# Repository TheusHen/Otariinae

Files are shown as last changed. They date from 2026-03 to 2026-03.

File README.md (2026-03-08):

# SeaLion (Otariinae)

SeaLion is my smart aquarium project. It started as “automate a few aquarium tasks” and turned into a full embedded system: custom PCB, separate controller boards, 3D structure, telemetry, relay control, local logging, aquaponics expansion, and a visual status matrix.

The project is intentionally split into two boards:

- **WhaleShark**: the main **ESP32** board that handles Wi‑Fi, API, time sync, automation, and system orchestration.
- **Flux**: the auxiliary **RP2040** board that handles local relays, the **MAX7219 8×8 matrix**, MicroSD logging, and hardware-side failsafe behavior.

I did it this way on purpose. I wanted networking and high-level logic on the main board, while the second board stays focused on the things that need to remain deterministic and safe near the hardware.

---

## What this project does

The goal is to keep the aquarium stable with as little manual work as possible.

That includes:

- continuous circulation
- water and environment monitoring
- relay control for pumps and other loads
- a local matrix display for loading, timers, warnings, and system state
- aquaponics expansion support
- local MicroSD logging
- remote control and telemetry through an HTTP API
- internet time sync through the ESP32 instead of an RTC on Flux

The aquaponics expansion in V1 is simple on purpose. It is basically a switchable timed peristaltic pump that pulls water from the aquarium and waters the plants. That logic lives in the automation layer and runs through a dedicated Flux relay output.

---

## Architecture

| Block | Controller | Role |
|---|---|---|
| WhaleShark | ESP32 | Wi‑Fi, API, NTP, automation, sensor aggregation, policy |
| Flux | RP2040 | Relay control, MAX7219 rendering, MicroSD logging, failsafe |
| Matrix | MAX7219 | Boot animations, status icons, scrolling text, timers |
| Aquaponics module | Flux relay output | Timed watering of the plant bed |

### Why this split exists

The ESP32 is the system brain. It is much better for:

- network access
- NTP time synchronization
- exposing an API
- coordinating all modules
- future dashboard integration

Flux is the hardware-side executor. It is better for:

- direct relay outputs
- keeping outputs alive in a safe state if the main board disappears
- driving the matrix without blocking the network stack
- logging locally on MicroSD

That separation also helps wiring. The noisy hardware can stay near the board that is meant to switch it.

---

## MAX7219 matrix

Flux controls an **8×8 matrix through the MAX7219**.

This matrix is not just decorative. It is used to display:

- loading during boot
- Wi‑Fi / ready / alert states
- timer countdowns
- short scrolling messages
- icons for pump, water, warning, and plant state

The firmware maps the matrix logically according to the schematic convention you used:

- rows: `ROW0` to `ROW7`
- columns: `COL7` to `COL0`

That means the firmware intentionally mirrors the logical X axis so the matrix behaves like the schematic view instead of whatever random hardware orientation would otherwise appear on the first try.

---

## Current V1 behavior

### Main aquarium pump

The main circulation pump is treated as a **normally-on output**.

That is the safest default for keeping water moving and helping filtration and oxygen exchange. In automatic mode, the firmware keeps it enabled unless there is a condition that strongly suggests protecting hardware from dry run, such as a low-level alarm.

### Aquaponics pump

The aquaponics expansion is handled by a dedicated Flux relay.

Default V1 policy:

- enabled during daytime window
- runs in short timed pulses
- skipped if the aquarium is in a low-level condition
- controlled by WhaleShark, switched by Flux

Those values are easy to change in the config files once the real flow rate is tested.

---

## Firmware layout

### WhaleShark / ESP32

Main responsibilities:

- connect to Wi‑Fi
- sync time from NTP
- read local sensors
- decide relay states
- expose HTTP API endpoints
- optionally protect endpoints with an API secret
- send commands and time updates to Flux over I2C

Important files:

- `firmware/ESP32/include/pins.h`
- `firmware/ESP32/include/config.h`
- `firmware/ESP32/src/main.cpp`

### Flux / RP2040

Main responsibilities:

- receive commands from WhaleShark over I2C
- drive relays
- drive the MAX7219 matrix
- log to MicroSD
- keep safe defaults if communication is lost

Important files:

- `firmware/RP2040(Flux)/include/pins.h`
- `firmware/RP2040(Flux)/include/config.h`
- `firmware/RP2040(Flux)/src/main.cpp`

Protocol notes:

- `firmware/PROTOCOL.md`

Board-to-board wiring notes:

- `docs/CONNECTIONS_FLUX_TO_WHALE.md`

---

## API

WhaleShark exposes a small V1 HTTP API.

Implemented endpoints:

- `GET /api/v1/ping`
- `GET /api/v1/status`
- `GET /api/v1/sensors`
- `POST /api/v1/mode?value=auto|manual|maintenance`
- `POST /api/v1/relay?name=main_pump|aquaponics|spare1|spare2&state=on|off`
- `POST /api/v1/matrix/text?text=HELLO`
- `POST /api/v1/matrix/timer?seconds=90`

### Optional secret

A V1 dashboard does not exist yet, but the firmware already supports an optional API secret.

Set `API_SECRET` in:

- `firmware/ESP32/include/config.h`

If it is set, requests must include:

- `X-API-Key: <your secret>`

If it is left empty, the API is open on the local network.

---

## Inter-board connection

The recommended connection for V1 is:

- I2C
- one interrupt/status line
- one enable/maintenance line
- shared ground
- 5V power from a single source

Recommended mapping:

| WhaleShark (ESP32) | Flux (RP2040) | Purpose |
|---|---|---|
| GPIO21 | GPIO4 | I2C SDA |
| GPIO22 | GPIO5 | I2C SCL |
| GPIO27 | GPIO14 | Flux interrupt / status |
| GPIO26 | GPIO15 | Flux enable / maintenance |
| 5V | VBUS / 5V in | power |
| GND | GND | common reference |

More detail is in:

- `docs/CONNECTIONS_FLUX_TO_WHALE.md`

---

## Mechanical side

The physical design uses a printed upper and lower structure with an acrylic middle body, mounting points, and space for cables, sensors, pumps, and boards.

### Structure 3D

<p align="center">
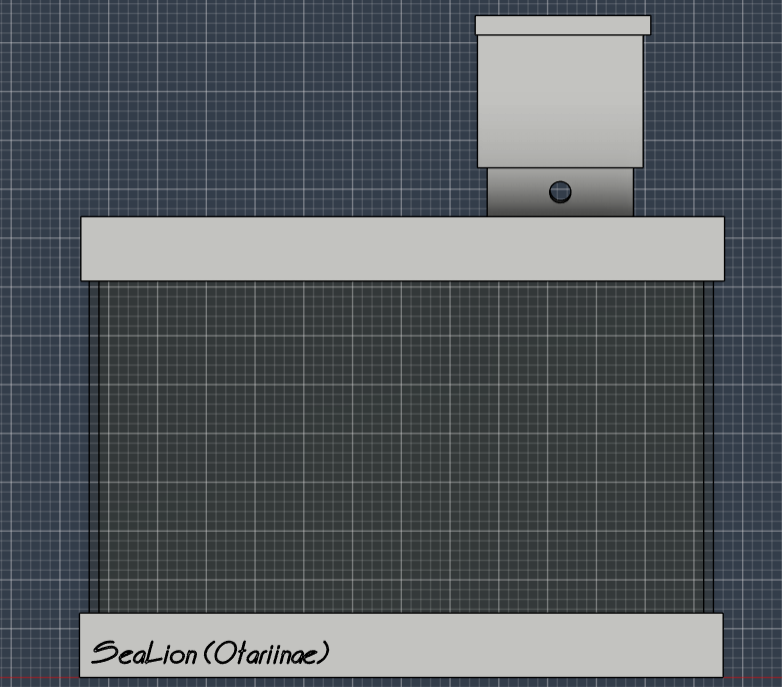
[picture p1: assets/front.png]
Front view
  
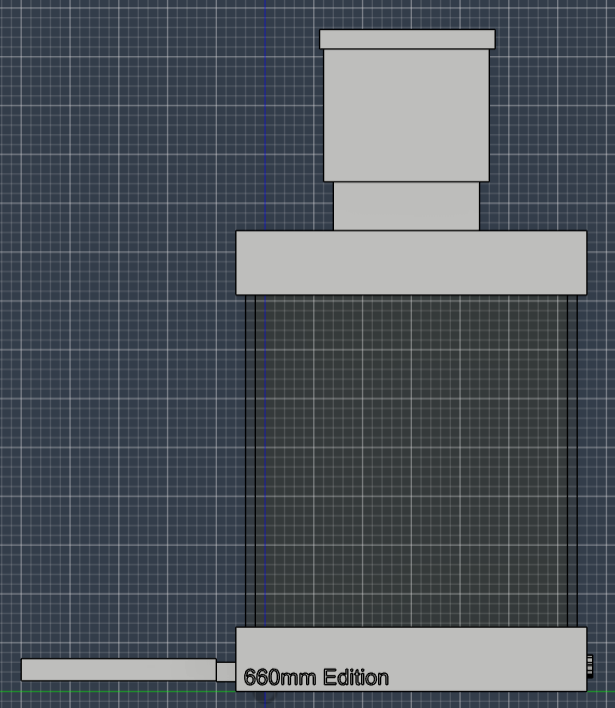
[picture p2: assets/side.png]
Side view
  
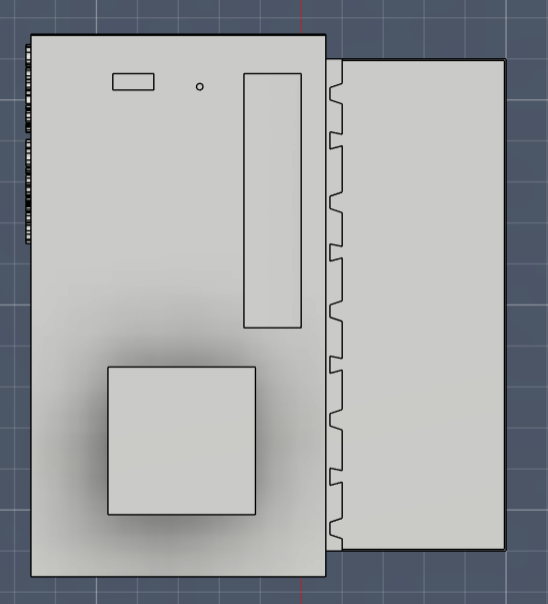
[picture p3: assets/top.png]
Top view
  
</p>

### Electrical bay

<p align="center">
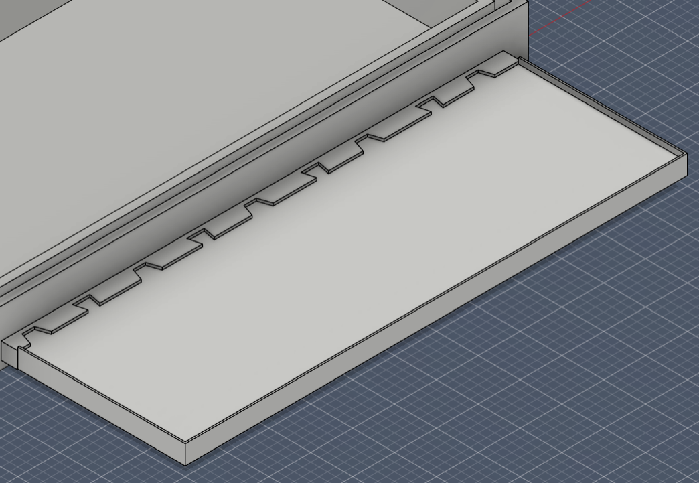
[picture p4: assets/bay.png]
Electrical bay
  
</p>

---

## PCB

### Schematic

<p align="center">
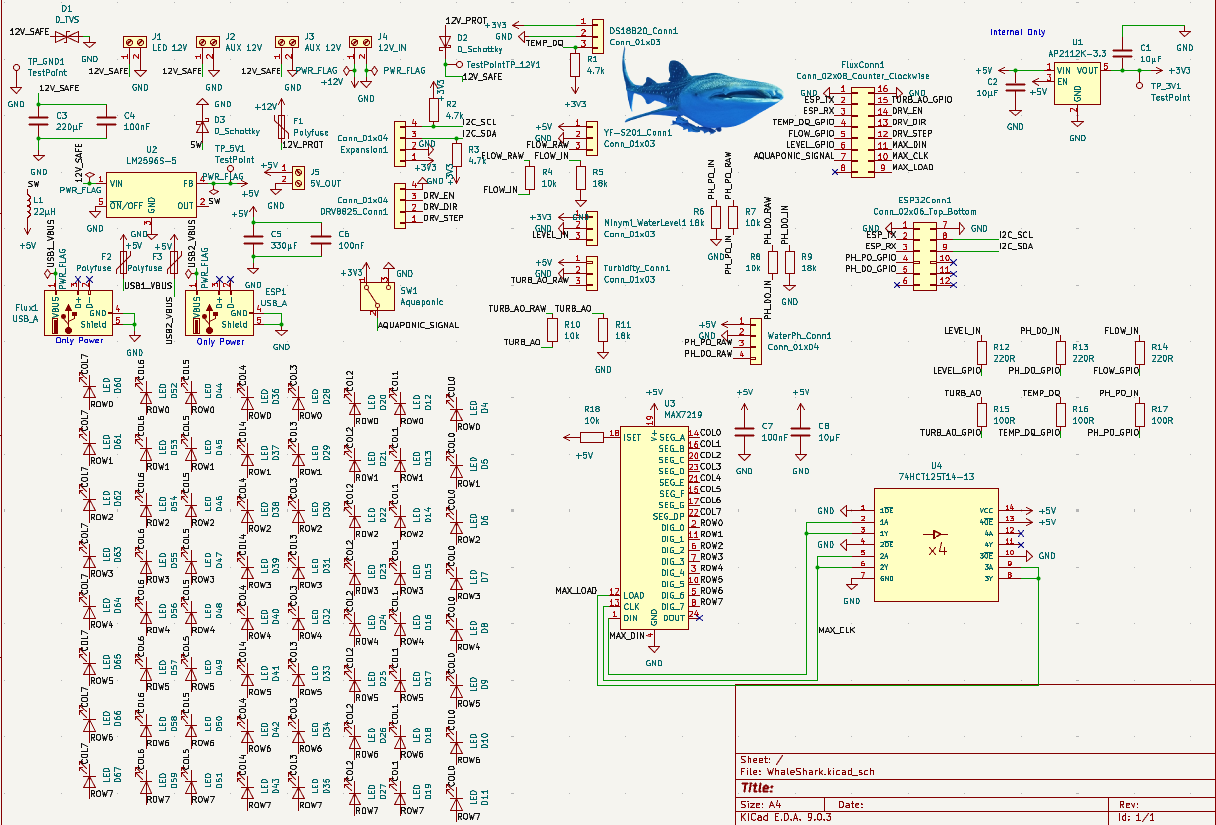
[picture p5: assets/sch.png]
WhaleShark schematic
  
</p>

### Layout

<p align="center">
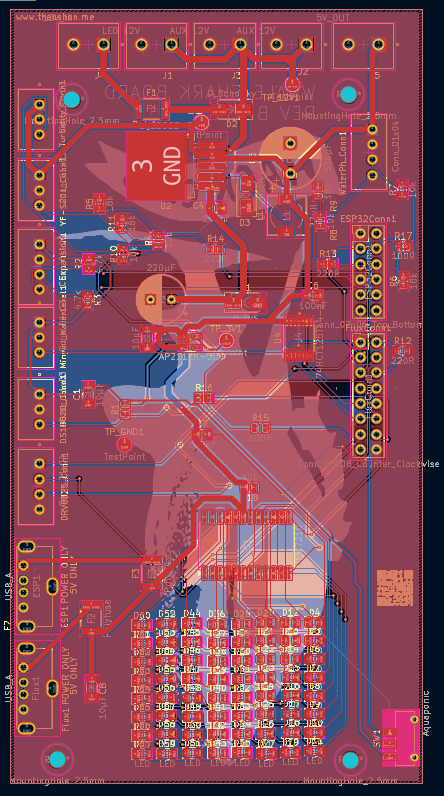
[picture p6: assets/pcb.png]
PCB layout
  
</p>

### Board 3D renders

<p align="center">
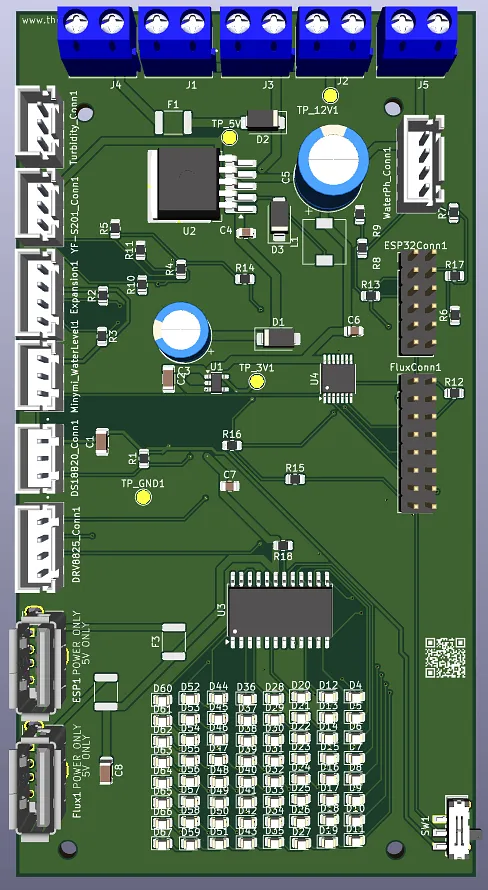
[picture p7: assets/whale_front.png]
PCB 3D front
  
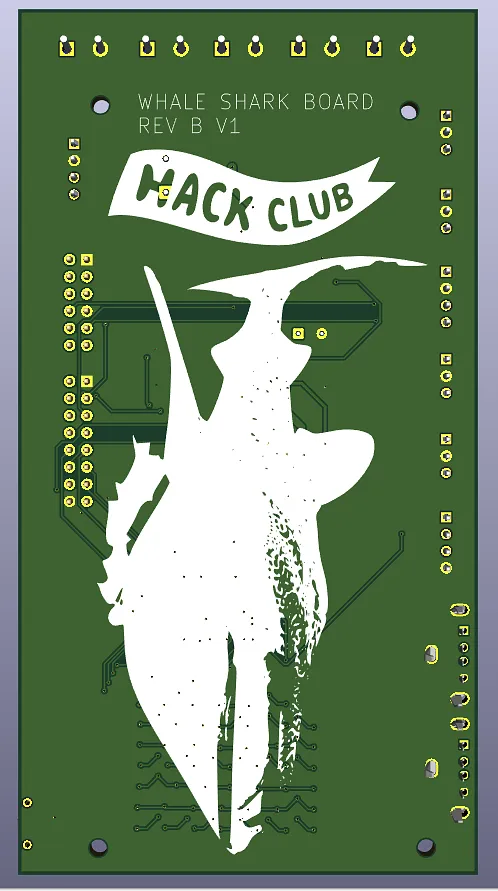
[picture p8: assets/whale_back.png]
PCB 3D back
  
</p>

---

## Notes about calibration

The firmware already includes the structure for:

- pH
- TDS
- turbidity
- water level
- water temperature

The analog conversions are present as practical V1 defaults, but they still need final real-world calibration against the exact probes and boards used in the hardware.

That part is normal. The project can boot, talk, switch, and show state without final calibration, but trustworthy chemistry values need calibration with the physical sensors.

---

## V1 priorities

The current focus is not a cloud product. The priority is:

1. boot reliably
2. connect both boards
3. read sensors
4. keep the aquarium alive safely
5. show useful local feedback on the matrix
6. expose a usable local API
7. leave room for a future dashboard

That is the point of this revision: get a strong first real hardware/software foundation instead of pretending the hard parts do not exist.

https://stpeter.im/writings/essays/publicdomain.html

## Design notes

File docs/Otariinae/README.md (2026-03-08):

# SeaLion — Otariinae (Visão geral do projeto)

SeaLion (edição **Otariinae**) é um aquário inteligente/autônomo com arquitetura embarcada **distribuída**, telemetria completa da água, automação e um módulo de **aquaponia** integrado.

**Fontes neste repositório**
- Escopo (Rev. C): [Need Some Fish — Rev C (Otariinae).md](../../Need%20Some%20Fish%20%E2%80%94%20Rev%20C%20(Otariinae).md)
- Devlog / histórico: [journal.md](../../journal.md)

---

## Nomes

| Item | Nome |
|---|---|
| Projeto | **SeaLion** |
| Edição | **Otariinae** |
| PCB | **WhaleShark** |

---

## Status / histórico (datas absolutas)

- **2026-03-03**: planejamento e “DataBook” Rev. A (ver [journal.md](../../journal.md)).
- **2026-03-04**: 3D (Fusion 360) e release Rev. B (ver [journal.md](../../journal.md)).
- **2026-03-05**: pesquisa e integração de **aquaponia** (ver [journal.md](../../journal.md)).
- **2026-03-06**: esquema e PCB WhaleShark (ver [journal.md](../../journal.md)).
- **2026-03-07**: TODOs / melhorias de power/segurança do PCB (ver [journal.md](../../journal.md)).

---

## Arquitetura eletrônica (distribuída)

A Rev. C adota 3 “blocos” independentes:

- **RP2040 DevBoard (Flux ou compatível)**: controle/IO, sensores, atuadores, **RTC** e **MicroSD**.
- **WhaleShark (PCB)**: distribuição elétrica, regulação, proteção, conectores/headers, drivers.
- **ESP32**: conectividade (Wi‐Fi / BLE / app), comunicação (ex.: UART) com o resto do sistema.

**DevBoard de controle (Flux)**

O projeto foi pensado para utilizar minha devboard custom chamada **Flux**, baseada no **RP2040**, que inclui:

- **Slot Micro SD**
- **Headers de IO expandidos**
- **Interface dedicada com a PCB WhaleShark**

Entretanto, o sistema não depende exclusivamente do **Flux**.

Durante desenvolvimento ou replicação do projeto, qualquer devboard compatível com **RP2040** pode ser utilizada, por exemplo:

- **Raspberry Pi Pico**
- **Pico W**
- **RP2040-Zero**
- outras placas **RP2040** compatíveis

Nesse caso, basta conectar a devboard ao header de controle da **WhaleShark PCB**.

---

## Sistema elétrico (alto nível)

Resumo do caminho de energia:

- Rede **110V** (fora do PCB) → filtro de linha com DPS → fonte **12V/10A (IP67)** → **WhaleShark PCB**
- No WhaleShark:
  - Buck **12V → 5V**
  - Regulador **3.3V**
  - Saídas 12V (LED, AUX, etc.)
  - Alimentação/headers para sensores

---

## Sensores (telemetria)

| Sensor | Função | Modelo/Referência |
|---|---|---|
| DS18B20 | Temperatura | DS18B20 à prova d’água |
| pH | Qualidade química | Módulo sensor + sonda BNC |
| Turbidez | Partículas | Sensor de turbidez (referência Arduino) |
| Fluxo | Circulação | YF‑S201 |
| Nível | Segurança de bomba | Sensor de nível (Minymix) |
| Vazamento | Proteção externa | Sensor Velds (Wi‑Fi, alarme 85 dBa) |

---

## Aquaponia (expansão)

Módulo de aquaponia com irrigação/circulação entre aquário e cultivo, e dosagem (bomba peristáltica).

Mitigações citadas: anti‑sifão, sensores de fluxo e nível, manutenção periódica.

---

## Dosador automático de comida

- Dosador rotativo impresso em 3D acionado por **motor NEMA17**
- Driver **DRV8825** (no WhaleShark)
- Controle de porção por passos do motor + agendamento via RTC (Flux)

---

## Estrutura mecânica (alto nível)

- Peças **3D** (parte superior e inferior)
- Seção transparente em **acrílico (PMMA)** encaixado entre as peças
- Compartimento elétrico integrado (mais rígido e simples)

Detalhes: [3D.md](3D.md)

---

## Onde está cada coisa (repo)

- Escopo (Rev. C): [Need Some Fish — Rev C (Otariinae).md](../../Need%20Some%20Fish%20%E2%80%94%20Rev%20C%20(Otariinae).md)
- Devlog: [journal.md](../../journal.md)
- 3D: pasta [3d](../../3d)
- PCB: [sch/WhaleShark.kicad_sch](../../sch/WhaleShark.kicad_sch) e [pcb/WhaleShark.kicad_pcb](../../pcb/WhaleShark.kicad_pcb)
- Gerbers/drill: [gerbers](../../gerbers) e [drl](../../drl)
- iBOM: [ibom/ibom.html](../../ibom/ibom.html)
- Imagens/renders: [assets](../../assets)

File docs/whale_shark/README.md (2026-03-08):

# WhaleShark PCB

A **WhaleShark** é a PCB de distribuição elétrica/regulação/proteção e interconexão do SeaLion (Otariinae).

Arquivos principais:
- Esquemático: [sch/WhaleShark.kicad_sch](../../sch/WhaleShark.kicad_sch)
- Layout: [pcb/WhaleShark.kicad_pcb](../../pcb/WhaleShark.kicad_pcb)
- iBOM: [ibom/ibom.html](../../ibom/ibom.html)

Fabricação:
- Gerbers: [gerbers](../../gerbers)
- Drill: [drl](../../drl)

Imagens:
- [assets/whale_front.png](../../assets/whale_front.png)
- [assets/whale_back.png](../../assets/whale_back.png)

---

## Parâmetros do PCB (do layout)

- Espessura: **1.6 mm** (ver [pcb/WhaleShark.kicad_pcb](../../pcb/WhaleShark.kicad_pcb))

---

## Blocos/ICs relevantes (confirmados no esquemático)

- Buck 12V→5V: **LM2596S-5**
- LDO 3.3V: **AP2112K-3.3**
- Driver LED: **MAX7219**
- Proteção: TVS (ex.: **D1 = D_TVS**)
- Polyfuses (PTC): **F1, F2, F3**

---

## Conectores de potência (bornes) — nomes no esquemático

- **J4 = 12V_IN** (entrada)
- **J1 = LED 12V** (saída 12V para LEDs)
- **J2 = AUX 12V**
- **J3 = AUX 12V**
- **J5 = 5V_OUT**

> Nota: a Rev. C descreve 2 saídas 12V (LED e AUX). O esquemático atual tem **duas** saídas AUX (J2 e J3). Confirme qual revisão você vai fabricar.

---

## USB-A (alimentação de devboards)

- **Flux1** (USB_A)
- **ESP1** (USB_A)

D+/D− aparecem como “unconnected” no layout (USB usado como alimentação, sem dados).

---

## Nets úteis (do layout)

Veja [pcb/WhaleShark.kicad_pcb](../../pcb/WhaleShark.kicad_pcb) para a lista completa; alguns nomes:

- Alimentação: **+12V**, **+5V**, **+3V3**, **GND**
- Stepper/driver: **/DRV_STEP**, **/DRV_DIR**, **/DRV_EN**, **/SW**
- MAX7219: **/MAX_CLK**, **/MAX_DIN**, **/MAX_LOAD**, **/ROW0..7**, **/COL0..7**
- I2C: **/I2C_SDA**, **/I2C_SCL**
- Aquaponia: **/AQUAPONIC_SIGNAL**
- ESP UART: **/ESP_RX**, **/ESP_TX**
- USB VBUS: **/USB1_VBUS**, **/USB2_VBUS**

---

## Gerbers e drill

- Gerbers: [gerbers](../../gerbers)
- Drill: [drl](../../drl)
- iBOM: [ibom/ibom.html](../../ibom/ibom.html)

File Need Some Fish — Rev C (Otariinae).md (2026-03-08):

# Need Some Fish — Rev. C (Otariinae)

Esse projeto virou praticamente um sistema embarcado completo para aquário inteligente. A ideia original era construir um aquário automático e elétrico do zero, e agora na Rev. C ele conta com: eletrônica dedicada, PCB custom, microcontroladores separados, múltiplos sensores, automação, aquaponia integrada, dosagem automática e conectividade.

---

## Visão geral da evolução

Desde a Rev. B, meu projeto evoluiu bastante. Saí de um conceito mais simples com Arduino ou microcontrolador único + relés + sensores com controle central, para uma arquitetura distribuída profissional com separação clara de responsabilidades, proteção elétrica completa, PCB custom roteada, telemetria da água e um módulo de aquaponia integrado.

---

## Arquitetura eletrônica (distribuída)

A maior mudança desse projeto foi sair de um controle central único para uma **arquitetura distribuída** com três sistemas independentes:

```
RP2040 DevBoard (Flux ou compatível)
        │
        │ IO / sensores / controle
        │
        ▼
WhaleShark PCB (distribuição elétrica)
        │
        │ UART / comunicação
        ▼
      ESP32
  WiFi / BLE / app
```

Separação clara de responsabilidades:

| Sistema | Função |
| --- | --- |
| **RP2040** | Controle de hardware  |
| **ESP32** | Conectividade |
| **WhaleShark** | Distribuição elétrica |

### RP2040 DevBoard (Flux ou compatível)

**DevBoard de controle (Flux)**

O projeto foi pensado para utilizar minha devboard custom chamada **Flux**, baseada no **RP2040**, que inclui:

- **Slot Micro SD**
- **Headers de IO expandidos**
- **Interface dedicada com a PCB WhaleShark**

Entretanto, o sistema não depende exclusivamente do **Flux**.

Durante desenvolvimento ou replicação do projeto, qualquer devboard compatível com **RP2040** pode ser utilizada, por exemplo:

- **Raspberry Pi Pico**
- **Pico W**
- **RP2040-Zero**
- outras placas **RP2040** compatíveis

Nesse caso, basta conectar a devboard ao header de controle da **WhaleShark PCB**.

O **ESP32** cuida exclusivamente de conectividade: Wi-Fi, BLE e integração com app/internet.

A **WhaleShark PCB** faz toda a distribuição elétrica, regulação de tensão e proteção entre os sistemas.

---

## Sistema elétrico (proteção completa)

Saí de um esquema simples de 110V → fonte → sensores para um sistema com proteção completa em cascata:

```
Tomada 110V
     │
Filtro de linha / DPS
     │
Fonte 12V 10A (IP67)
     │
PCB WhaleShark
     │
Buck 12V → 5V
     │
Regulador 3.3V
```

### Proteções implementadas

- **Fusível** na entrada
- **Polyfuse (PTC)** nas saídas
- **Proteção de polaridade** (contra inversão)
- **TVS** (contra surtos)
- **Separação física de tensões** no PCB
- **DPS** no filtro de linha (antes da fonte)

Isso reduz muito o risco de falha elétrica, especialmente considerando que esse projeto trabalha perto de água.

### Caminho completo da energia

```
Tomada Quarto (110V)
  → Chave geral bipolar
    → Filtro de Linha com DPS
      → Fonte AC-DC 12V 10A (IP67)
        → Terminal block do PCB WhaleShark
          → Buck 12V→5V (USBs para Flux + ESP32)
          → Saídas 12V (LED, AUX, Motor)
          → Headers de sensores (3.3V/5V)
```

### Componentes de alimentação

- **Filtro de linha com DPS** — iCLAMPER Energia 5 (127/220V, 10A, 5 tomadas)
- **Fonte AC→DC** — FONTE BLINDADA FC FONTES 12V 10A 120W IP67 FC1210BN
- **Cabo de força** — Rabicho 2p + T 2,50mm Plugue 10A 1,50m 127/220V
- **Chave geral** — Módulo Interruptor Bipolar Simples 25A Inova Pro Class Alumbra

---

## PCB WhaleShark (custom)

Esse é um dos maiores upgrades do projeto. Saí de fios soltos, módulos avulsos e jumpers para uma **PCB custom** com roteamento adequado.

### O que a PCB tem

- Reguladores de tensão integrados
- Headers organizados para cada sensor/atuador
- Drivers integrados (DRV8825 para motor de passo)
- Buck converter com layout correto
- Divisores de tensão seguros
- Pull-ups I2C
- Trilhas de potência grossas
- Distribuição de energia separada por função
- **Test points** para facilitar depuração e manutenção

### Alimentação e proteção (no PCB)

- **Entrada principal:** 1x borne 2 vias (12V_IN)
- **Fusível/Polyfuse (PTC)** na entrada 12V
- **Proteção contra inversão de polaridade** na entrada
- **2x portas USB-A** para alimentar Flux + ESP32 (via DC-DC buck 12V→5V)
- **Polyfuse (PTC)** em 5V por porta

### Saídas 12V (alta corrente)

1. **1x borne 2 vias** — LED 12V
2. **1x borne 2 vias** — AUX 12V (reserva)

### Motor de passo (dosador)

- **Driver DRV8825** (soldado no PCB)
- Conector do motor: **JST-XH 4 vias**

### Headers de sensores

| Sensor | Header |
| --- | --- |
| DS18B20 | 1x 3 vias (V/G/D) |
| YF-S201 (fluxo)  | 1x 3 vias |
| Nível (Minymix) | 1x 3 vias |
| Turbidez | 1x 3 vias |
| Módulo de pH | 1x 3 ou 4 vias |
| I2C (expansão) | 1x 4 vias (V/G/SDA/SCL) |

### Conectores entre placas

- **Flux ↔ WhaleShark (controle):** 1x header 2x8 (16 pinos)
- **ESP32 ↔ WhaleShark (comunicação):** 1x header 2x6 (12 pinos)

Isso coloca meu projeto num nível de engenharia muito mais alto do que módulos soltos com jumper.

---

## Sistema de sensores (telemetria completa)

Saí de monitoramento básico para **telemetria completa da água**. Agora consigo monitorar em tempo real tudo que importa.

| Sensor | Função | Modelo/Referência |
| --- | --- | --- |
| DS18B20 | Temperatura | DS18B20 à prova d'água |
| pH | Qualidade química | Módulo Sensor + pH Eletrodo Sonda BNC |
| Turbidez | Partículas na água | Sensor De Turbidez Arduino |
| Fluxo | Circulação | YF-S201 |
| Nível | Segurança da bomba | Sensor De Nível De Água (Minymix) |
| Vazamento  | Proteção externa | Sensor Velds (WiFi, Alarme 85dBa) |

Com isso consigo:
- **Monitoramento em tempo real** de todos os parâmetros
- **Alarmes** automáticos (vazamento, nível baixo, pH fora da faixa)
- **Histórico** de dados (via SD no Flux)
- **Automação** baseada nas leituras (ex: desligar bomba se nível cair)

---

## Aquaponia (nova adição — Rev. C)

Essa foi uma grande expansão do meu projeto. Agora o sistema também controla um módulo de **aquaponia integrado**:

- **Irrigação** das plantas
- **Circulação de água** entre aquário e área de cultivo
- **Dosagem de nutrientes** (via bomba peristáltica)

### Benefícios

- Reciclagem de nutrientes da água do aquário
- Crescimento de plantas como filtragem natural
- Filtragem biológica complementar

### Riscos que estou tratando

| Problema | Risco | Mitigação |
| --- | --- | --- |
| Sifão | Drenagem reversa | Anti-sifão implementado  |
| Entupimento  | Bloqueio de fluxo | Sensor de fluxo (YF-S201) |
| Evaporação | Queda de nível | Sensor de nível |
| Biofilme | Interferência nos sensores | Manutenção periódica |

Já comecei a tratar o problema de sifão com válvula anti-sifão, e os sensores de fluxo e nível ajudam a detectar os outros problemas automaticamente.

---

## Dosador automático de comida

Meu sistema de dosagem usa um **dosador rotativo impresso em 3D** acionado por motor de passo, muito mais confiável que soluções com servo.

```
Reservatório (tampa vedada)
     │
Dosador rotativo (3D)
     │
Motor NEMA 17
     │
Driver DRV8825 (no PCB)
```

### Vantagens

- **Controle fino de porção** (por passos do motor)
- **Alimentação programada** (via Internet, ESP32)
- **Confiabilidade** muito maior que servo simples (sem travar/fechar portinha)

### Estrutura mecânica do dosador

- No topo, fiz em 3D uma **"bacia"/reservatório** que encaixa num buraco acima da tampa.
- Esse reservatório tem **tampa própria** para isolar a ração da umidade.
- A ração fica totalmente isolada até o dosador rotativo liberar a porção, e então cai para dentro do aquário.

### Componentes

- **Motor** — NEMA 17 1.3A 2,8kg (CNC/Laser/Impressora 3D)
- **Driver** — DRV8825 (integrado no PCB WhaleShark)

---

## Estrutura mecânica

### Materiais e estrutura geral

- Preciso de **alta resistência à água** em todas as conexões.
- A estrutura é em peças **3D** (parte de baixo e parte de cima).
- A parte transparente do aquário, no meio entre as duas partes 3D, é feita de **acrílico (PMMA)** para encaixar nas peças impressas.

### Compartimento elétrico (evolução)

Inicialmente eu planejava uma baia removível com trilhos e sistema de gaveta (detalhes na Rev. B). Depois, simplifiquei para:

- **Dovetail fixo**
- **Compartimento integrado** na peça 3D
- **60 cm de largura**

Essa mudança foi boa porque:
- Aumenta a **rigidez** do conjunto
- Reduz **vibração**
- Evita **desalinhamento** mecânico
- Menos peças = menos pontos de falha

### Passagem de cabos e sensores

Na parte de cima, deixo **furos/canais** para passagem de:
- Sensores que vão dentro da água
- Cabos dos LEDs da tampa
- Demais cabos que precisarem descer para o compartimento elétrico

---

## Componentes controlados via GPIO

- **Filtro interno** (via módulo de relé) — Filtro Interno Ipf 408 Aquario Pequeno 30 Litros Aleas 127V
- **Fita de LED** (na tampa, fora da água, bem isolada) — Fita LED MK 10W/m COB IP65
  - *Aviso:* IP65 ajuda contra respingos/umidade, mas não é para imersão. Como fica perto de água, uso isolação extra (perfil/capa, boa vedação e prensa-cabos) e evito emendas expostas.
- **Motor de passo** (dosador) — NEMA 17 via DRV8825

---

## Segurança

Apliquei várias boas práticas de segurança, especialmente considerando que é um sistema com água:

- **Separar 110V do PCB** — a tensão de rede não passa pelo meu PCB
- **Usar 12V como padrão** — todo o aquário trabalha em baixa tensão
- **Fonte isolada (IP67)** — proteção contra respingos
- **Proteção contra inversão de polaridade** — no PCB
- **Sensores de vazamento** — na base, fora do aquário (com alarme 85dBa + WiFi)
- **Fusíveis e polyfuses** — em múltiplos pontos do circuito
- **TVS** — proteção contra surtos
- **Chave geral bipolar** — corta tudo antes da fonte

---

## Manutenção e expansibilidade

Meu design atual permite:

- **Trocar sensores** facilmente (headers padronizados)
- **Expandir via I2C** (header de expansão dedicado)
- **Adicionar módulos** sem refazer o PCB
- **Testar facilmente** (test points no PCB)
- **Acessar o compartimento elétrico** (dovetail fixo, abertura traseira)

Os test points que adicionei no PCB ajudam muito na depuração e manutenção do sistema.

---

## Consumíveis e montagem (geral)

- Abraçadeira de nylon
- Prensa-cabo
- Terminais ilhós
- Conectores WAGO
- Fusíveis sobressalentes
- Fios com bitola adequada
- Tubo termo-retrátil
- Silicone neutro próprio para aquário

### Componentes extra (mecânica / montagem)

- **Rolamento 608zz Código 210046-0** (2x)
- **Parafuso Pequeno M3 8 M3x8 M3 X 8 Mm Inox A2 — 20pçs**
- **Cola Silic. 50g Trans. aquário Tekb**

---

## Nomes

| Nome | Referência |
| --- | --- |
| Projeto | **SeaLion** |
| Edition | **Otariinae** |
| PCB | **WhaleShark** |

---

*Need Some Fish — Rev. C (Otariinae)*

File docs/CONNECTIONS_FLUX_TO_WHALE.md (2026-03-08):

# Flux ↔ WhaleShark connection plan

This document defines the recommended V1 interconnect between the **Flux** board (RP2040) and the **WhaleShark** board (ESP32).

The goal here is not just “make the boards talk”, but to make the wiring safe, debuggable, and compatible with normal ESP32 boot behavior.

## Design choice

For V1, the cleanest inter-board link is:

- **I2C** for control and telemetry
- **1 interrupt/status line** from Flux to WhaleShark
- **1 enable/maintenance line** from WhaleShark to Flux
- **shared ground**
- **single-source 5V power**, with Flux regulating itself to 3.3V through its onboard regulator

I2C was chosen because Flux already exposes dedicated I2C pins on the schematic, it keeps wiring simple, and it is enough for relay control, state reporting, log coordination, time sync, and matrix commands.

## Recommended ESP32 pins on WhaleShark

These pins were selected to avoid common ESP32 boot/strapping trouble:

| WhaleShark (ESP32) | Role | Why |
|---|---|---|
| GPIO21 | I2C SDA | Standard ESP32 I2C SDA choice |
| GPIO22 | I2C SCL | Standard ESP32 I2C SCL choice |
| GPIO27 | FLUX_INT | Safe digital input, not a boot strap pin |
| GPIO26 | FLUX_ENABLE | Safe digital output, not a boot strap pin |
| 5V rail | Flux power input | Lets Flux use its onboard 3.3V regulator |
| GND | Common reference | Mandatory for logic integrity |

## Confirmed Flux pins from the schematic image

From the Flux schematic image, the following pins are already clearly defined:

| Flux signal | RP2040 GPIO |
|---|---|
| I2C0_SDA | GPIO4 |
| I2C0_SCL | GPIO5 |
| SD_MISO | GPIO16 |
| SD_CS | GPIO17 |
| SD_SCK | GPIO18 |
| SD_MOSI | GPIO19 |
| SD_DET | GPIO20 |

The relay and matrix assignments below are the V1 firmware defaults:

| Flux function | RP2040 GPIO |
|---|---|
| Main aquarium pump relay | GPIO10 |
| Aquaponics peristaltic pump relay | GPIO11 |
| Spare relay 1 | GPIO12 |
| Spare relay 2 | GPIO13 |
| Flux interrupt/status to WhaleShark | GPIO14 |
| Flux enable / maintenance input from WhaleShark | GPIO15 |
| MAX7219 DIN | GPIO6 |
| MAX7219 CLK | GPIO7 |
| MAX7219 CS | GPIO8 |

## Final wiring: board to board

### Required lines

| WhaleShark pin | Connect to Flux pin | Direction | Notes |
|---|---|---|---|
| GPIO21 | GPIO4 (I2C0_SDA) | bidirectional | I2C data |
| GPIO22 | GPIO5 (I2C0_SCL) | output/clock | I2C clock |
| GPIO27 | GPIO14 | Flux → Whale | Optional but recommended; signals fault, new log state, or heartbeat edge |
| GPIO26 | GPIO15 | Whale → Flux | Lets WhaleShark place Flux in maintenance-safe mode |
| 5V | VBUS / 5V input | power | Use only one 5V source at a time |
| GND | GND | reference | Required |

### Optional lines

| WhaleShark pin | Connect to Flux pin | Purpose |
|---|---|---|
| GPIO25 | RUN or spare reset conditioning circuit | Optional hard reset strategy for Flux |
| GPIO33 | Spare ADC monitor | Optional voltage / current monitor return if you add it later |

## Power notes

### Recommended V1 power model

- Feed the whole system from one main regulated **5V rail**.
- WhaleShark uses its own 3.3V domain.
- Flux receives **5V on VBUS / 5V input**, then its onboard regulator generates **3.3V**.
- Both boards must share **GND**.

### Important

Do **not** power Flux from both:

- USB-C **and**
- WhaleShark 5V interconnect

at the same time unless you intentionally add power-path protection.

For development, use either:

- Flux by USB-C alone, or
- system 5V rail through the interconnect

## Why these ESP32 pins were chosen

The ESP32 has several pins that are tied to boot behavior or internal flash, so they are bad candidates for inter-board control if avoidable.

Avoid for this link whenever possible:

- GPIO0
- GPIO2
- GPIO5
- GPIO12
- GPIO15
- GPIO6 to GPIO11
- GPIO1 and GPIO3 if you still want easy serial debugging

That is why the plan uses **GPIO21 / GPIO22 / GPIO26 / GPIO27** on WhaleShark.

## Internal V1 role split

### WhaleShark owns

- Wi-Fi
- NTP / internet time
- high-level automation state
- HTTP API
- secret-protected control endpoints
- consolidated sensor state
- long-term scheduling decisions

### Flux owns

- relay switching
- MAX7219 display rendering
- MicroSD logging
- local failsafe behavior
- keeping outputs in a safe state if WhaleShark disappears

## Recommended harness

For the interconnect cable, use a dedicated 6-pin or 8-pin harness:

### Minimum 6-pin

1. 5V
2. GND
3. SDA
4. SCL
5. FLUX_INT
6. FLUX_ENABLE

### Better 8-pin

1. 5V
2. GND
3. SDA
4. SCL
5. FLUX_INT
6. FLUX_ENABLE
7. spare
8. spare

This leaves room for future fault lines, analog return, or wake/reset.

## MAX7219 note

The MAX7219 is controlled locally by Flux, not by WhaleShark directly. That is intentional.

WhaleShark should only send high-level instructions such as:

- boot animation
- scroll text
- loading state
- warning icon
- timer countdown mode
- maintenance mode

Flux then translates that into actual matrix drawing.

## V1 expected behavior

On boot:

1. Flux powers up.
2. Flux brings relays to safe defaults.
3. Flux initializes the MAX7219 and shows a local boot animation.
4. WhaleShark boots, joins Wi-Fi, gets time, initializes sensors.
5. WhaleShark sends a time sync and display state to Flux.
6. Flux switches from local boot mode to commanded runtime mode.

That gives the project a cleaner startup sequence and avoids depending on Wi-Fi before showing life on the matrix.

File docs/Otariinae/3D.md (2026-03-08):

# SeaLion — Otariinae (3D)

Arquivos 3D do projeto SeaLion (edição Otariinae) e notas de fabricação/montagem.

Fontes de contexto:
- Escopo mecânico (Rev. C): [Need Some Fish — Rev C (Otariinae).md](../../Need%20Some%20Fish%20%E2%80%94%20Rev%20C%20(Otariinae).md)
- Devlog (3D Rev. B): [journal.md](../../journal.md)

---

## Arquivos

Pasta: [3d](../../3d)

- Fusion 360: [SeaLion (Otariinae).f3d](../../3d/SeaLion%20(Otariinae).f3d)
- STL: [SeaLion (Otariinae).stl](../../3d/SeaLion%20(Otariinae).stl)
- Showcase: [Showcase.obj](../../3d/Showcase.obj) + [Showcase.mtl](../../3d/Showcase.mtl)

Imagens:
- [assets/front.png](../../assets/front.png)
- [assets/side.png](../../assets/side.png)
- [assets/top.png](../../assets/top.png)
- [assets/bay.png](../../assets/bay.png)

---

## Conceito mecânico (resumo)

- Estrutura em **peças 3D** (parte de baixo e parte de cima).
- Seção transparente em **acrílico (PMMA)** encaixado entre as partes impressas.
- Compartimento elétrico integrado.
- Furos/canais na tampa para passagem de:
  - sensores submersos
  - cabos dos LEDs
  - cabos para o compartimento elétrico

---

## Dosador rotativo (impressão + montagem)

Conjunto impresso em 3D acionado por motor de passo (NEMA17), com porcionamento por passos e reservatório com tampa para reduzir umidade.

Itens mecânicos citados no escopo:
- Rolamento **608zz** (2x)
- Parafusos **M3x8**
- Silicone neutro próprio para aquário

---

## Notas práticas (genéricas)

- Planeje segmentação/cortes para caber na sua impressora.
- Priorize vedação (prensa‑cabos, silicone, evitar emendas expostas em zonas úmidas).
- Faça testes de encaixe do PMMA antes da montagem final.

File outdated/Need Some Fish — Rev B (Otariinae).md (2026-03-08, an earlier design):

# Need Some Fish — Rev. B (Otariinae)

A ideia aqui é construir um aquário automático e elétrico, do zero.

### Componentes Extra (mecânica / montagem)

- **Rolamento 608zz Código 210046-0** (2x)
- **Parafuso Pequeno M3 8 M3x8 M3 X 8 Mm Inox A2 - 20pçs**
- **Cola Silic. 50g Trans.aquario Tekb**

### Materiais e estrutura

- Vamos precisar de alguns sensores e componentes.
- Precisamos de **alta resistência à água** em todas as conexões.
- A estrutura será em peças **3D** (parte de baixo e parte de cima).
- A parte transparente do aquário, que fica no meio entre as duas partes 3D, será feita de **acrílico (PMMA)** para encaixar nas peças impressas.
- Também vamos usar bombas, servos e conexão à internet.

### Estrutura externa (fora da água)

- Na parte de baixo (peça 3D), atrás do aquário, vai existir uma **baia/compartimento 3D externo** para colocar todo o **sistema elétrico**.
- Essa baia vai servir para organizar:

#### ~~Baia removível (gaveta) + trilho impresso~~

- **~~Posição:** atrás, embaixo, **escondida**.~~
- **~~Remoção:** **100% removível** (toda a elétrica fica na baia).~~
- **~~Material sugerido:** **PETG** (mais resistente a temperatura e umidade do que PLA).~~
- **~~Largura alvo:** ~**40 cm** (altura pode ser a que couber, mantendo folga para cabos e conectores).~~

**~~Arquitetura do trilho~~**

- ~~Fazer **dois trilhos paralelos** (esquerda + direita) integrados na peça 3D do aquário.~~
- ~~A baia entra por trás e desliza até encostar no batente.~~
- ~~Perfil do trilho:~~
    - ~~Preferência: **dovetail leve (trapezoidal)** para não “cair” e reduzir folga.~~
    - ~~Alternativa mais simples: **canal em U + patim** (mais fácil, mas tende a ter mais folga).~~

**~~Travamento / fixação no final do curso (para não soltar sozinho)~~**

- ~~Batente mecânico no fim do trilho.~~
- ~~1 ponto de retenção (escolher 1):~~
    - **~~Trava por clip (snap-fit)** na frente da baia.~~
    - **~~1 parafuso** (M3/M4) de retenção.~~
    - **~~Ímãs + batente** (segura fechado e fica elegante).~~

**~~Detalhes importantes (pra não dar ruim)~~**

- **~~Folga de impressão:** começar com ~**0,4 mm por lado** e ajustar conforme a impressora (PETG costuma “engordar” um pouco).~~
- **~~Anti-torção:** usar os 2 trilhos + uma “aba” frontal (ou guia central) para a baia não virar quando puxar.~~
- **~~Puxador/pegador:** recorte ou alça para remover sem enroscar nos cabos.~~
- **~~Alívio de cabos:** zona interna para fazer “loop” e não puxar conector.~~
- **~~Passagem selada:** usar **prensa-cabos** na saída da baia.~~
- **~~Ventilação:** se a fonte e relés aquecerem, prever respiros na baia (sem ficar aberto para respingo).~~

**~~Layout interno da baia (peso médio)~~**

- ~~Separar em 2 “andares” ou 2 zonas:~~
    - **~~Potência/AC (entrada, fusível, fonte)** bem isolado e fixo.~~
    - **~~Baixa tensão (12 V, WAGO, distribuição, relés, conexões)** com acesso fácil.~~
    - ~~(Opcional) Uma “tampinha” interna para cobrir bornes e evitar toque acidental.~~
    - ~~a fonte AC → DC~~
    - ~~régua com fusível~~
    - ~~módulos (relés, conversores, etc.)~~
    - ~~conexões e distribuição de energia para bombas, LEDs e sensores~~

Completamente feito no 3D, Ficou 60cm de largura, e Dovetail somente.

### Passagem de cabos e sensores

- Na parte de cima, vamos deixar **furos/canais** para passagem de:
    - sensores que vão dentro da água
    - cabos dos LEDs da tampa
    - demais cabos que precisarem descer para a baia elétrica

### Placa de controle

- Vamos usar **duas placas**: **Flux (RP2040)** + **ESP32 (de fábrica)**.
- **Mudança importante:** o **Flux não tem conectividade**. Então **Wi‑Fi/BLE e tudo que for comunicação** fica por conta do **ESP32**.
- **RP2040 DevBoard (Flux ou compatível)**

**DevBoard de controle (Flux)**

O projeto foi pensado para utilizar minha devboard custom chamada **Flux**, baseada no **RP2040**, que inclui:

- **Slot Micro SD**
- **Headers de IO expandidos**
- **Interface dedicada com a PCB WhaleShark**

Entretanto, o sistema não depende exclusivamente do **Flux**.

Durante desenvolvimento ou replicação do projeto, qualquer devboard compatível com **RP2040** pode ser utilizada, por exemplo:

- **Raspberry Pi Pico**
- **Pico W**
- **RP2040-Zero**
- outras placas **RP2040** compatíveis

Nesse caso, basta conectar a devboard ao header de controle da **WhaleShark PCB**.
- O **ESP32** será usado como módulo de conectividade e integração com a internet/app.

### Observações importantes (montagem)

- Já saiba que vamos soldar bastante coisa e usar bastante fita isolante, principalmente no **módulo de relé** etc.

Mas como todo o aquário trabalha em baixa tensão, a parte da fonte é separada, 110V não passa pelo nosso PCB

### Segurança elétrica / alimentação

- A parte que vem da tomada (110 V) vai entrar em uma **régua com fusível** (proteção).
- Vamos usar uma **fonte AC → DC** para transformar **110 V em 12 V,** que vai ser o padrão utilizado pelo aquário.
- **Todo o aquário trabalha em baixa tensão** (12 V), para reduzir riscos e evitar problemas.

### Componentes que serão controlados via GPIO

- Régua com fusível, antes da fonte, dá energia 110V para a Bomba por exemplo e passa para a fonte
    - **Filtro de linha com protetor contra surtos 
    (DPS) - 127/220 volts - 10 amperes - 5 tomadas - 3 pinos - iCLAMPER 
    Energia 5 - LCF - Transparente**
- Filtro interno (via **módulo de relé**).
    - **Filtro Interno Ipf 408 Aquario Pequeno 30 Litros  Aleas 127V**
- LED ou fita de LED (na tampa, **fora da água** e bem isolado).
    - **Fita LED MK 10W/m COB IP65**
    - *Aviso:* IP65 ajuda contra respingos/umidade, mas **não é para imersão**. Como fica perto de água, prefira sempre **isolação extra** (perfil/capa, boa vedação e prensa-cabos) e evitar emendas expostas.
- Sensor de temperatura (à prova d’água).
    - **DS18B20**
- Sensor de **pH** da água.
    - **Módulo Sensor + Ph Eletrodo Sonda Bnc**
- Sensor de **turbidez**.
    - **Sensor De Turbidez Arduino Para Monitoramento Dágua**
- Sensor de fluxo.
    - **YF-S201**
- **Sensor de nível de água** (para impedir a bomba de rodar a seco).
    - **Sensor De Nível De Água E Chuva Para Arduino - Minymix**
- Sensor de vazamento (na base, do lado de fora do aquário).
    - **Sensor de vazamento de água Velds (WiFi, Notificação Instantânea, Alarme de 85dBa, Baixo Consumo) - VDS SVAW**
- **Motor de passo** (aciona o dosador rotativo de comida).
    - **Motor De Passo Nema 17 1.3a 2,8 Kg Cnc Laser Impressora 3d**
- Chave geral (corta toda a energia, precisa ser colocada antes da bomba e da fonte, ou seja na 110V, precisa se boa isolação, e cuidado, 
operar com o polo negativo).
    - **Módulo Interruptor Bipolar Simples 25 A Inova Pro Class Alumbra**
- Fonte AC → DC
    - **FONTE BLINDADA FC FONTES 12V 10A 120W IP67 FC1210BN**
- Adaptador, tomada filtro de linha → Fonte
    - **Cabo De Força Rabicho 2p + T 2,50mm Plugue 10a 1,50 Metro 127/220v**
- Consumíveis e montagem (geral)
    - **Abraçadeira de nylon**
    - **Prensa-cabo**
    - **Terminais ilhós**
    - **Conectores WAGO**
    - **Fusíveis sobressalentes**
    - **Fios com bitola adequada**
    - **Tubo termo-retrátil**
    - **Silicone neutro próprio para aquário**

### Dispenser de comida (tampa superior)

- No topo, vou fazer em 3D uma **“bacia”/reservatório** que encaixa em um buraco acima da tampa do dosador.
- Esse reservatório vai ter uma **tampa própria**, para evitar que a ração fique úmida.
- A ração fica totalmente isolada até o **dosador rotativo (impresso em 3D)** liberar a porção, e então a ração cai para dentro do aquário.
- O dosador vai ser acionado por **motor de passo**, para ter controle fino da quantidade (passos) e evitar problemas de travar/fechar de “portinha”.

### PCB / conexões

- PCB já pronta, com vários **pin headers**.
- Resistores e proteções já feitos para conectar diretamente os pinos dos componentes, relés, etc., à **Flux DevBoard**.

#### Alimentação e proteção

- **Entrada principal:** 1x **borne 2 vias (12V_IN)**
- **Fusível/Polyfuse (PTC) na entrada 12V**
- **Proteção contra inversão de polaridade** (na entrada 12V)
- **2x portas USB-A** para alimentar as duas placas (Flux + ESP32)
    - Alimentação via **DC-DC buck 12V → 5V**
    - **Polyfuse (PTC)** em 5V (por porta ou geral)

#### Saídas 12V (alta corrente / fio mais grosso)

1. **1x borne 2 vias – LED 12V**
2. **1x borne 2 vias – AUX 12V** *(sobrando)*

#### Motor de passo (dosador)

- **Driver DRV8825** (no PCB, como componente)
- Conector do motor: **JST-XH 4 vias** (preferível)

#### Headers de sensores

- **DS18B20 (à prova d’água):** 1x header 3 vias (V/G/D)
- **YF-S201 (fluxo):** 1x header 3 vias
- **Sensor de nível (Minymix):** 1x header 3 vias
- **Turbidez:** 1x header 3 vias
- **Módulo de pH:** 1x header 3 ou 4 vias (depende do módulo: AO/DO)
- **I2C “expansão”:** 1x header 4 vias (V/G/SDA/SCL)

#### Conectores entre placas

- **Para Flux ↔ WhaleShark (controle):** 1x header **2x8 (16 pinos)**
- **Para ESP32 ↔ WhaleShark (comunicação):** 1x header **2x6 (12 pinos)**

Tomada Quarto(110V) → Filtro de Linha(Sistema 110V) → Fonte AC DC(Terminal block) → **12V** → Terminal block do PCB → Headers pins e Terminal Blocks → Sensores/Relay da Bomba/Fita de led/Motor de Passo

Fora isso, é só fazer um sistema de monitoramento conectado à Flux DevBoard, e pronto.

# Nomes

Projeto: **SeaLion**
Edition: **Otariinae**
PCB: **WhaleShark**

[Need Some Fish — Rev. B (Otariinae) — EN](https://www.notion.so/Need-Some-Fish-Rev-B-Otariinae-EN-74aa7f24469a47aab4f081518cf3b9b8?pvs=21)

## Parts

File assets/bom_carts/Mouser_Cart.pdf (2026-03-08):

CARRINHO DE COMPRAS | Isto não é uma fatura.

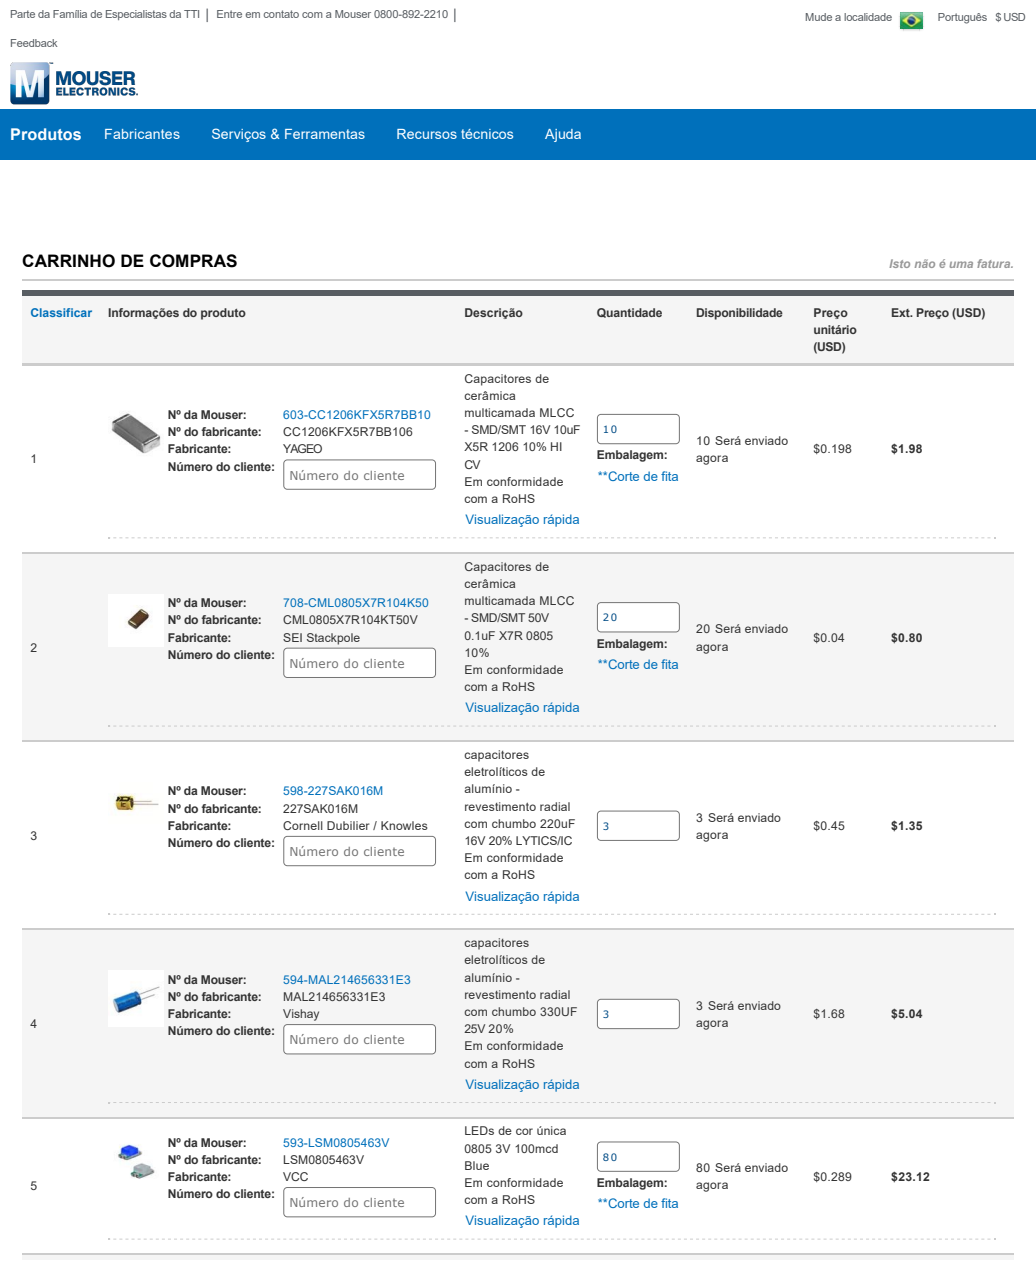
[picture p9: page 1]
Nº da Mouser:; 603-CC1206KFX5R7BB10; Nº do fabricante:; CC1206KFX5R7BB106; Fabricante:; YAGEO; Capacitores de; cerâmica; multicamada MLCC; SMD/SMT 16V 10uF; Em conformidade; com a RoHS; 10 Será enviado; agora; 708-CML0805X7R104K50; CML0805X7R104KT50V; SEI Stackpole; SMD/SMT 50V; 20 Será enviado; 598-227SAK016M; 227SAK016M; Cornell Dubilier / Knowles; capacitores; eletrolíticos de; alumínio; revestimento radial; com chumbo 220uF; 16V 20% LYTICS/IC; 3 Será enviado; 594-MAL214656331E3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

Parte da Família de Especialistas da TTI (https://br.mouser.com/about-tti/) | Entre em contato com a Mouser 0800-892-2210 (https://br.mouser.com/contact/)

Ext. Preço (USD)

Número do cliente:

Embalagem:
**Corte de fita

Número do cliente

LEDs de cor única
0805 3V 100mcd
Blue
Em conformidade
com a RoHS
Visualização rápida

Blocos de terminais
fixos 2P 5.08mm
90DEG
Compatível com
RoHS por isenção

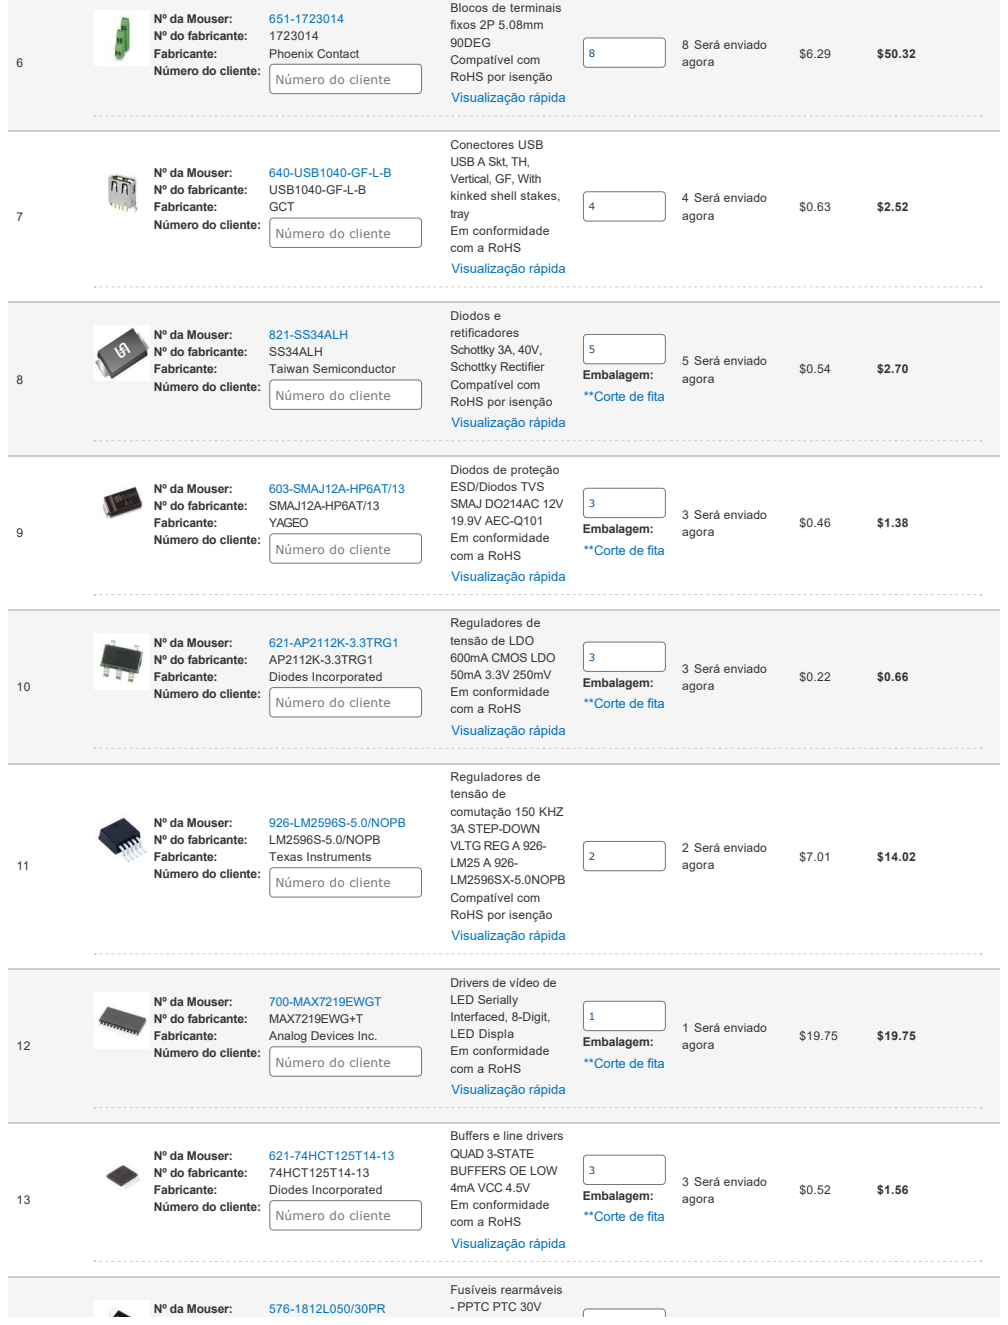
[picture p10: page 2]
Nº da Mouser:; Nº do fabricante:; Fabricante:; Phoenix Contact; 640-USB1040-GF-L-B; USB1040-GF-L-B; GCT; 4 Será enviado; agora; 821-SS34ALH; SS34ALH; Taiwan Semiconductor; 5 Será enviado; 603-SMAJ12A-HP6AT/13; SMAJ12A-HP6AT/13; YAGEO; 3 Será enviado; 621-AP2112K-3.3TRG1; AP2112K-3.3TRG1; Diodes Incorporated; 926-LM2596S-5.0/NOPB; LM2596S-5.0/NOPB; Texas Instruments; 2 Será enviado; 700-MAX7219EWGT; MAX7219EWG+T; Analog Devices Inc.; 1 Será enviado; 621-74HCT125T14-13; 74HCT125T14-13; Littelfuse

Blocos de terminais
fixos 2P 5.08mm
90DEG
Compatível com
RoHS por isenção
Visualização rápida

Conectores USB
USB A Skt, TH,
Vertical, GF, With
kinked shell stakes,
tray
Em conformidade
com a RoHS

Número do cliente:

Número do cliente

Diodos e
retificadores
Schottky 3A, 40V,
Schottky Rectifier

Embalagem:
**Corte de fita

Diodos de proteção
ESD/Diodos TVS
SMAJ DO214AC 12V
19.9V AEC-Q101

Reguladores de
tensão de LDO
600mA CMOS LDO

tensão de
comutação 150 KHZ
3A STEP-DOWN
VLTG REG A 926-
LM2596SX-5.0NOPB

Drivers de vídeo de
LED Serially
Interfaced, 8-Digit,
LED Displa

Buffers e line drivers
QUAD 3-STATE
BUFFERS OE LOW
4mA VCC 4.5V

Fusíveis rearmáveis
PPTC PTC 30V
POLY SURF MOUNT

Nº do fabricante: | 1812L050/30PR
Fabricante: | Littelfuse

POLY SURF MOUNT
1812 .500A
Em conformidade
com a RoHS
$0.90 | $5.40
Nº da Mouser: | 306-B3BXHALFSNP (https://br.mouser.com/ProductDetail/JST/B3B-XH-ALFSN?qs=cdbOS8ANM9BVkoboCCIEMQ%3D%3D)
Nº do fabricante: | B3B-XH-A(LF)(SN)
Fabricante: | JST
Número do cliente:

Distribuidores e
Alojamento de Fios
XH HEADER (TOP)
Em conformidade
com a RoHS

6

0 Será enviado
agora
6 Pendências do
pedido (https://br.mouser.com/Search/include/aoopopup)
$0.11 | $0.66
Nº da Mouser: | 306-B4BXHALFSN (https://br.mouser.com/ProductDetail/JST/B4B-XH-ALFSN?qs=cdbOS8ANM9CfC08d%252BywhFw%3D%3D)
Nº do fabricante: | B4B-XH-A(LF)(SN)
Fabricante: | JST
Número do cliente:

Distribuidores e
Alojamento de Fios
XH HEADER (TOP)
Em conformidade
com a RoHS

6

6 Será enviado
agora
$0.14 | $0.84

Visualização rápida

15

Visualização rápida

16

Visualização rápida

Embalagem:
**Corte de fita

Ao enviar este pedido, você concorda como seguinte termos e condições. (https://br.mouser.com/saleterms)
Para obter mais informações sobre a disponibilidade, clique no nº de ref. da Mouser.

**Todos os itens MouseReel™ não poderão ser cancelados nem devolvidos.

Incoterms: FCA (retenção de impostos de importação, taxas alfandegárias e contribuições no ato da entrega).

Mercadoria: | | $132.10
Remessa: | UPS Worldwide Express Saver | $35.00

Existem itens de pedido em atraso no seu carrinho. Você poderá fazer seleções adicionais na finalização do pedido.

Subtotal de: | $167.10

Finalizar compra

Número do cliente

Número do cliente

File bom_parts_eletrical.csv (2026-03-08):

Product | Qty. | Unit Price | Total Price | URL
Rolamento 608zz Código 210046-0 Makita Original | 2 | R$ 18,80 | R$ 37,60 | https://www.mercadolivre.com.br/rolamento-608zz-codigo-2100460-makita-original/up/MLBU3548005871
Parafuso Aço M3x8mm Inox A2 Cabeça Cilíndrica Belenus 20 Pçs | 20 | R$ 1,13 | R$ 22,61 | https://www.mercadolivre.com.br/parafuso-aco-m3x8mm-inox-a2-cabeca-cilindrica-belenus-20-pcs/up/MLBU1728157628
Silicone Acético Transparente Tekbond 50g Vedação Vidro | 2 | R$ 14,15 | R$ 28,30 | https://www.mercadolivre.com.br/silicone-acetico-transparente-tekbond-50g-vedacao-vidro/up/MLBU3635637178
Filtro De Linha + DPS Iclamper 5 Tomadas LCF | 1 | R$ 69,99 | R$ 69,99 | https://www.mercadolivre.com.br/filtro-de-linha--dps-iclamper-5-tomadas-lcf-transparente/up/MLBU2033877036
Filtro Interno IPF 408 Aquário Pequeno 30 Litros Aleas | 1 | R$ 41,90 | R$ 41,90 | https://www.mercadolivre.com.br/filtro-interno-ipf-408-aquario-pequeno-30-litros-aleas/p/MLB22768122
Fita LED COB 10W/m 12V 320LED/m + Fonte 5A | 1 | R$ 66,48 | R$ 66,48 | https://produto.mercadolivre.com.br/MLB-4013731609-fita-led-cob-10wm-12v-320ledm-irc80-3000k-ip65-fonte-5a-_JM
Sensor Temperatura DS18B20 + Módulo Adaptador | 1 | R$ 36,95 | R$ 36,95 | https://www.mercadolivre.com.br/sensor-temperatura-ds18b20-a-prova-dagua--modulo-adaptador/up/MLBU1467486302
Módulo Sensor pH + Eletrodo BNC | 1 | R$ 169,99 | R$ 169,99 | https://www.casadarobotica.com/sensores-modulos/sensores/outros/modulo-sensor-ph-eletrodo-sonda-bnc-sensor-de-ph-da-agua
Sensor de Turbidez Arduino | 1 | R$ 121,21 | R$ 121,21 | https://www.mercadolivre.com.br/sensor-de-turbidez-arduino-para-monitoramento-dagua/up/MLBU1444897199
Sensor Fluxo Vazão Água YF-S201 | 1 | R$ 32,00 | R$ 32,00 | https://www.mercadolivre.com.br/sensor-de-fluxo-vazo-agua-12-yf-s201-arduino-efeito-hall/p/MLB27392154
Sensor Nível Água Arduino | 1 | R$ 9,90 | R$ 9,90 | https://www.mercadolivre.com.br/sensor-nivel-agua-arduino-montimport-profundidade/p/MLB61745919
Detector Vazamento Água WiFi | 1 | R$ 149,90 | R$ 149,90 | https://www.mercadolivre.com.br/detector-vazamento-de-agua-velds-wifi-c-alarme-e-aplicativo/up/MLBU3181345437
Motor de Passo Nema 17 1.3A | 1 | R$ 60,75 | R$ 60,75 | https://produto.mercadolivre.com.br/MLB-3947539365-motor-de-passo-nema-17-13a-28-kg-cnc-laser-impressora-3d-_JM
Interruptor Bipolar 25A | 1 | R$ 39,25 | R$ 39,25 | https://www.mercadolivre.com.br/interruptor-bipolar-alumbra-25a-linha-inova-pro-branco/p/MLB28572096
Fonte Chaveada 12V 10A IP67 | 1 | R$ 188,00 | R$ 188,00 | https://www.mercadolivre.com.br/fonte-chaveada-fc-fontes-12v-10a-120w-blindada-ip67-aluminio/p/MLB34122250
Cabo de Força 2P+T 1.5m | 1 | R$ 39,50 | R$ 39,50 | https://www.mercadolivre.com.br/cabo-de-forca-rabicho-2p--t-250mm-plugue-10a-150-metro/up/MLBU1750521180
Abraçadeiras Nylon 100pcs | 1 | R$ 10,90 | R$ 10,90 | https://a.co/d/00ajxSVW
Conectores Wago 221-612 (kit) | 1 | R$ 14,48 | R$ 14,48 | https://a.co/d/066xS34E
Driver DRV8825 Stepper | 1 | R$ 19,50 | R$ 19,50 | https://www.mercadolivre.com.br/driver-para-motor-de-passo-drv8825-bipolar-impressora-3d-cnc/up/MLBU3509243412

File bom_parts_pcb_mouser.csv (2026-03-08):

Index | Mouser Part | Manufacturer Part | Manufacturer | Description | Qty | Unit Price USD | Total USD
1 | 603-CC1206KFX5R7BB10 | CC1206KFX5R7BB106 | YAGEO | 10uF 1206 MLCC Capacitor | 10 | 0.198 | 1.98
2 | 708-CML0805X7R104K50 | CML0805X7R104KT50V | SEI Stackpole | 100nF 0805 MLCC Capacitor | 20 | 0.04 | 0.80
3 | 598-227SAK016M | 227SAK016M | Cornell Dubilier | 220uF Electrolytic Capacitor | 3 | 0.45 | 1.35
4 | 594-MAL214656331E3 | MAL214656331E3 | Vishay | 330uF Electrolytic Capacitor | 3 | 1.68 | 5.04
5 | 593-LSM0805463V | LSM0805463V | VCC | 0805 Blue LED | 80 | 0.289 | 23.12
6 | 651-1723014 | 1723014 | Phoenix Contact | Terminal Block 2P 5.08mm | 8 | 6.29 | 50.32
7 | 640-USB1040-GF-L-B | USB1040-GF-L-B | GCT | USB A Vertical Connector | 4 | 0.63 | 2.52
8 | 821-SS34ALH | SS34ALH | Taiwan Semiconductor | Schottky Diode 3A 40V | 5 | 0.54 | 2.70
9 | 603-SMAJ12A-HP6AT/13 | SMAJ12A-HP6AT/13 | YAGEO | TVS Diode 12V SMAJ | 3 | 0.46 | 1.38
10 | 621-AP2112K-3.3TRG1 | AP2112K-3.3TRG1 | Diodes Inc. | 3.3V LDO Regulator | 3 | 0.22 | 0.66
11 | 926-LM2596S-5.0/NOPB | LM2596S-5.0/NOPB | Texas Instruments | 5V Buck Regulator | 2 | 7.01 | 14.02
12 | 700-MAX7219EWGT | MAX7219EWG+T | Analog Devices | LED Matrix Driver | 1 | 19.75 | 19.75
13 | 621-74HCT125T14-13 | 74HCT125T14-13 | Diodes Inc. | Quad Buffer IC | 3 | 0.52 | 1.56
14 | 576-1812L050/30PR | 1812L050/30PR | Littelfuse | Polyfuse 1812 0.5A | 6 | 0.90 | 5.40
15 | 306-B3BXHALFSNP | B3B-XH-A | JST | JST XH 3 Pin Header | 6 | 0.11 | 0.66
16 | 306-B4BXHALFSN | B4B-XH-A | JST | JST XH 4 Pin Header | 6 | 0.14 | 0.84

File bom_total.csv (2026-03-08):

Category | Value
Electrical Components BRL | R$ 1.230,49
Electrical Components USD | $234.62
Mouser Components USD | $132.10
PCB Manufacturing USD | $4.80
Total USD | $371.52

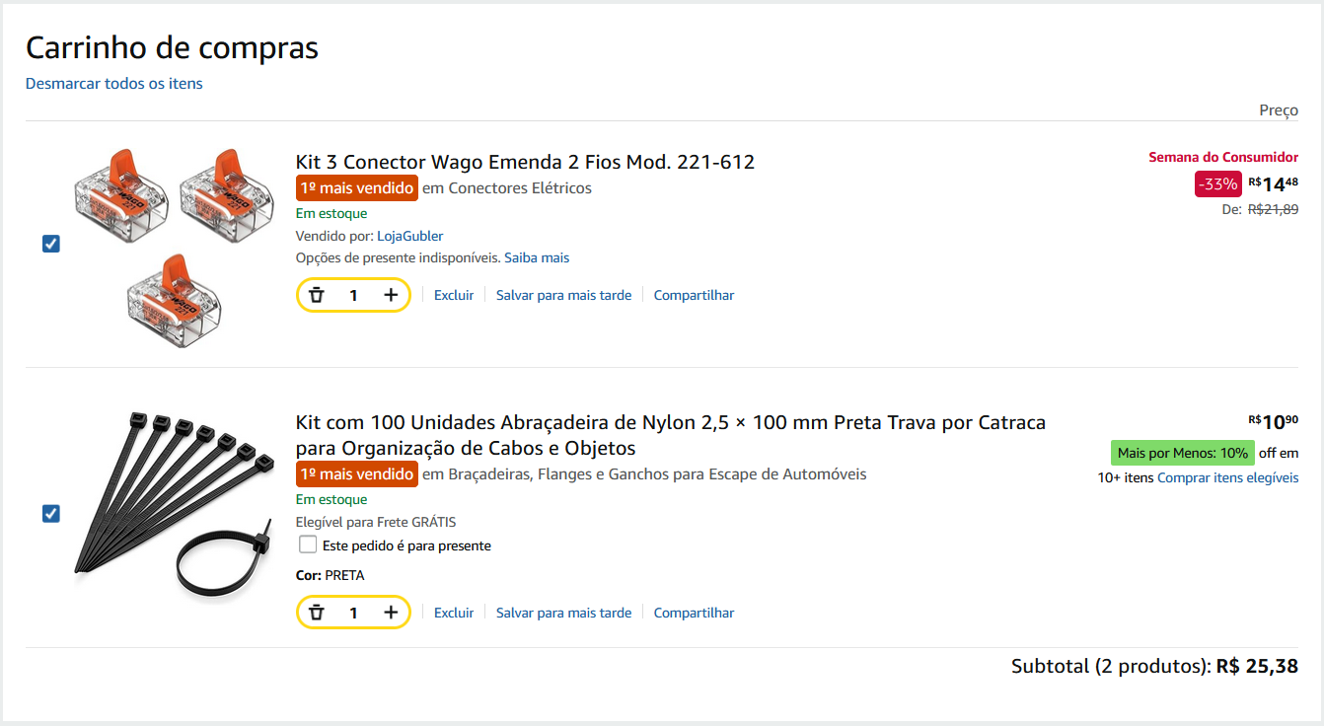
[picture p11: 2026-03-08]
assets/bom_carts/Amazon.png

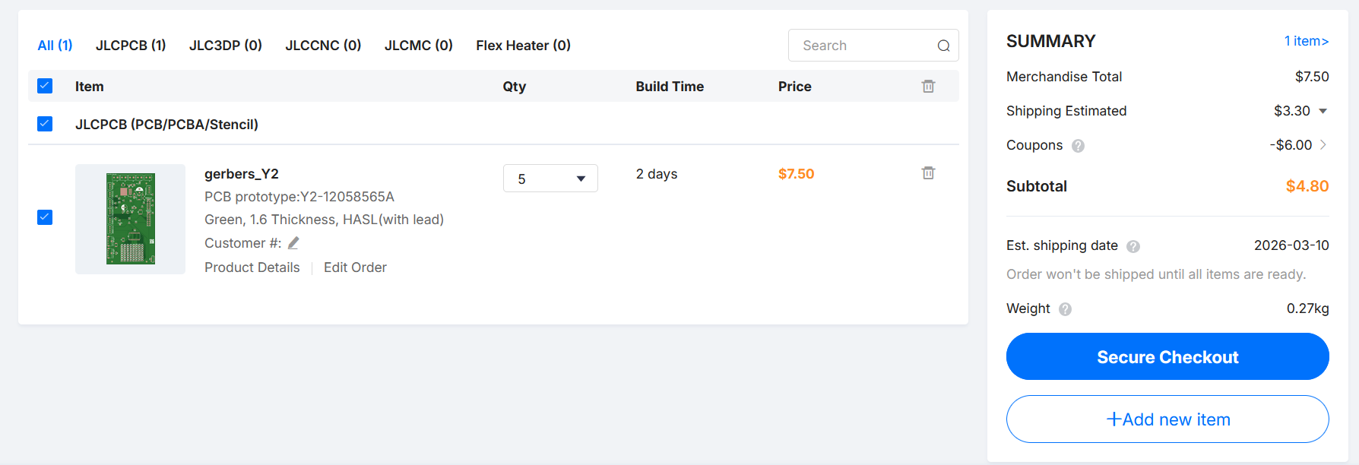
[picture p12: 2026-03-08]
assets/bom_carts/JLCPCB.png

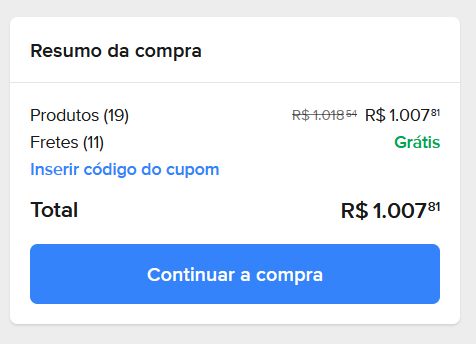
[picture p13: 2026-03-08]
assets/bom_carts/Mercado_Livre.png

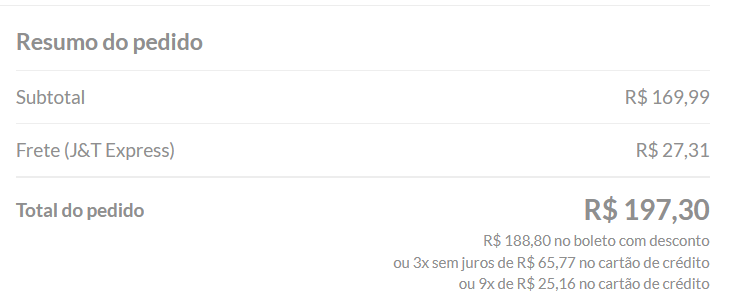
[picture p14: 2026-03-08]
assets/bom_carts/Casa_Robotica.png

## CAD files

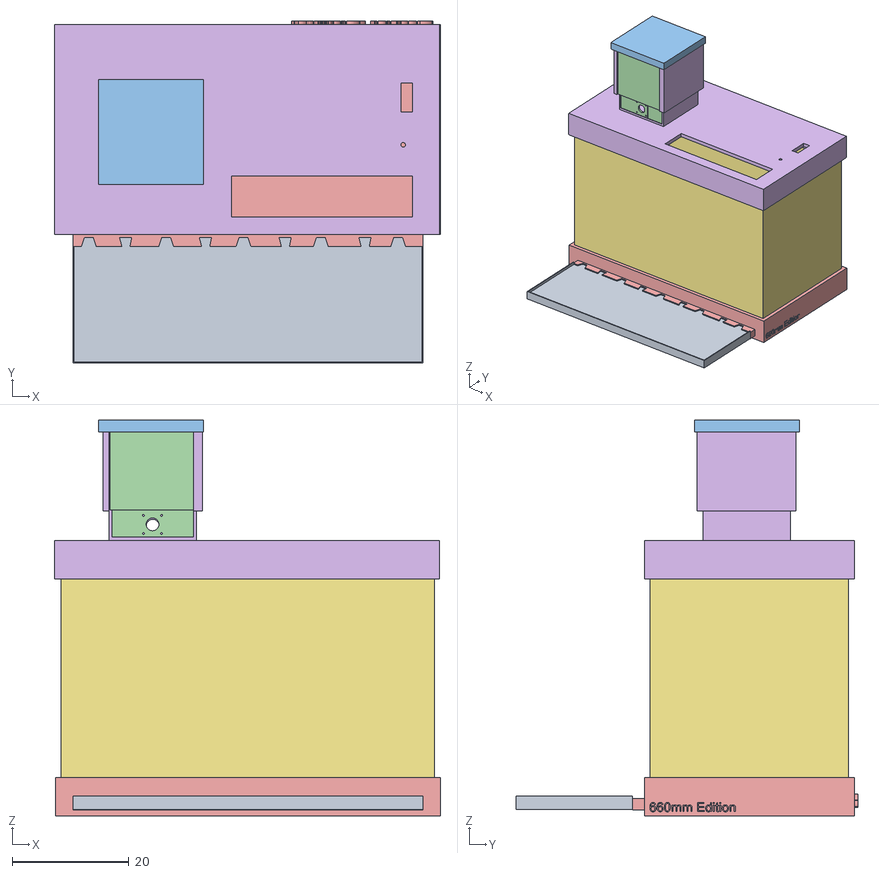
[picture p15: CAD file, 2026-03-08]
3d/Showcase.obj
66.1 x 58.6 x 67.8
Corpo36
Corpo38
Corpo39
Corpo40
Corpo35
Corpo37
Corpo41

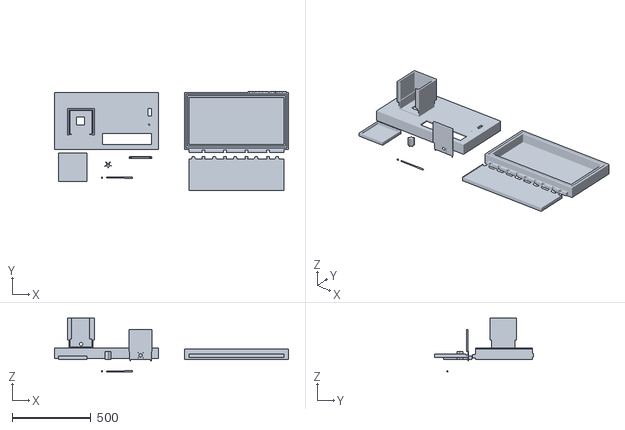
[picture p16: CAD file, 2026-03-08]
3d/SeaLion (Otariinae).stl
1483.4 x 626.0 x 342.0

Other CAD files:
3d/SeaLion (Otariinae).f3d

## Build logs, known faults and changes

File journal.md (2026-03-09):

<!--
  This journal is auto generated by Hack Club Blueprint.
-->

# 3/3/2026 - Just Released Rev. A DataBook  

_Time spent: 10.0h_  



I completely planned how we’re going to build our autonomous aquarium from scratch. The exact dimensions haven’t been decided yet, but I already have a rough idea of how I’m going to structure everything around them.

I accidentally knocked over a cup of water on my PC while writing this, SeaLion vibes.

It took me about two days to finish this Notion, but I genuinely believe I covered everything that actually needed to be covered.

PT-BR:
[8d38ce83-3bd9-4603-ae11-4a4049196776_Need_Some_Fish__Rev._a_(otariinae)](/user-attachments/blobs/proxy/eyJfcmFpbHMiOnsiZGF0YSI6MTE0NjQ3LCJwdXIiOiJibG9iX2lkIn19--f026a8de2663c36be7dd8e5cd03f163bd386755e/8d38ce83-3bd9-4603-ae11-4a4049196776_Need_Some_Fish__Rev._a_(otariinae).pdf)

EN-US:
[690e3eea-6413-4bfc-b6b2-8d47628d4bda_Need_Some_Fish__Rev._a_(otariinae)__en](/user-attachments/blobs/proxy/eyJfcmFpbHMiOnsiZGF0YSI6MTE0NjU3LCJwdXIiOiJibG9iX2lkIn19--cb401b4e8c8354a3d6c1130e929b59933f575204/690e3eea-6413-4bfc-b6b2-8d47628d4bda_Need_Some_Fish__Rev._a_(otariinae)__en.pdf)  

# 3/4/2026 - Created 3D(Fusion 360) and Launched Rev.B  

_Time spent: 20.0h_  

I know, a full 3D in 2 days is insane, but I'm insane (or just crazy), but I did it anyway. I hope reviewers read this: I created 3D thinking that I intend to print it myself. My only desire is to get a 3D printer at the blueprint shop, which is why I didn't do it. I'll cut out the large pieces when I print it, maybe change some sizes, and try again. Silicone will be indispensable for this. I encourage you to read the Rev. B PDF. I hope it has everything you need.

Now I need to move on to the PCB and start making our Whale Shark!






This one is really interesting. It took me a while to make it:
![image] (/user-attachments/blobs/proxy/eyJfcmFpbHMiOnsiZGF0YSI6MTE1MzA0LCJwdXIiOiJibG9iX2lkIn19--a3376acb35e6cda5eda18d6129034cd41215ac4c/image.png)

Basically, one end is placed on the shaft of our motor and secured with silicone. The outer ends are thicker to fit the bearings embedded in the 3D model to allow rotation. It is responsible for making the rotary collector system spin and the food fall to the fish.

Sorry for this poor review of changes, I'm really tired, and I have a test tomorrow.
EN-US:
[bc94b5c7-fccc-4843-9255-07d2726bed05_Need_Some_Fish__Rev._b_(otariinae)__en](/user-attachments/blobs/proxy/eyJfcmFpbHMiOnsiZGF0YSI6MTE1MzE0LCJwdXIiOiJibG9iX2lkIn19--45620652321b792a57c0d10ff1ec885eecd4fd7f/bc94b5c7-fccc-4843-9255-07d2726bed05_Need_Some_Fish__Rev._b_(otariinae)__en.pdf)

PT-BR:
[0125515d-9364-4407-b029-74fa296e1033_Need_Some_Fish__Rev._b_(otariinae)](/user-attachments/blobs/proxy/eyJfcmFpbHMiOnsiZGF0YSI6MTE1MzE1LCJwdXIiOiJibG9iX2lkIn19--864aac2e0777b571714c8de8c60016e7076ddbbe/0125515d-9364-4407-b029-74fa296e1033_Need_Some_Fish__Rev._b_(otariinae).pdf)

# 3/5/2026 - Something interesting, aquaponics  

_Time spent: 2.2h_  

I've been doing some research and got some feedback on the project. I spent this afternoon researching aquaponics and how it could be interesting for my project, and honestly, it seems incredible. I had already thought about adding expansion modules to SeaLion from the beginning, and aquaponics seems quite interesting, so I decided to add a port for aquaponics as an extra, an expansion.

Aquaponics basically consists of:

![image] (/user-attachments/blobs/proxy/eyJfcmFpbHMiOnsiZGF0YSI6MTE1Nzc4LCJwdXIiOiJibG9iX2lkIn19--129a28be92db76f6128ec12fbd267929bcddaf47/image.png)
With fish farming, the nutrients deposited by the fish are left behind so that this water with fish nutrients can be used for the plants. I intend to do this using a mini peristaltic pump, but for that, I will still need to work on the 3D design, create a basket where our plantation will be, and a pipe to collect filtered water from the plants and return it to the aquarium.

Diagrams of the holes in the lid:


I added the size spec in 3D as well:
![image] (/user-attachments/blobs/proxy/eyJfcmFpbHMiOnsiZGF0YSI6MTE1NzUzLCJwdXIiOiJibG9iX2lkIn19--a9eecf569ec93c3cdbd62400f15d119cd513c199/image.png)  

# 3/6/2026 6 PM - Finished WhaleShark Schematic  

_Time spent: 14.0h_  

I just finished designing our PCB schematic, and I don't think I'll be making many changes. Now I need to add the footprints for each component.

As you can see, I tried to invest heavily in safety for a V1. I'm using only one Polyfuse for the entire 12V. Ideally, there would be one per 12V port, but I'm not allowing myself that luxury. Maybe that would be something for V2 or later. I added two USB-A ports, both for connecting the Devboards. They don't transmit DATA, so the firmware must be placed on a PC to be connected only by the board.

In total, our board manages 12V, 5V, and 3.3V. The 110V is isolated and outside the board. It is transformed into 12V to enter the board.





# 3/6/2026 11 PM - Added Footprints and created PCB  

_Time spent: 5.4h_  

I added all the footprints and created the PCB. It's still Rev. A of the PCB, so there may be changes, perhaps related to electrical safety or similar.

The most tedious part was organizing these LEDs.
![image] (/user-attachments/blobs/proxy/eyJfcmFpbHMiOnsiZGF0YSI6MTE2OTEyLCJwdXIiOiJibG9iX2lkIn19--cb59b01e7376269596f2e14dd08dc88f18f9ea9c/image.png)

I tried to arrange the LEDs for the PCB, but we still have some problems. To solve them, I will recreate the correct formatting for each LED in the firmware. Even if it is not in the ROW and COL order, I will recreate it in the firmware so that we can make the LED work and show the status of our aquarium.

I had to fix some DRC errors, but everything passed.

Layout done:




3D:

  

# 3/7/2026 12 AM - More a ToDo than a Devlog, *beeps* *beeps*  

_Time spent: 0.3h_  

# 1. Power Routing Improvements
Priority: HIGH

## Increase trace width
Current traces: ~0.20 mm

Update to:

| Net | Recommended Width |
|----|----|
| Signal lines | 0.20–0.25 mm |
| 3.3V | 0.30–0.40 mm |
| 5V main rail | 0.80–1.00 mm |
| 12V rail | 1.20–2.00 mm |

### Tasks
- [x] Identify all `+12V` nets
- [x] Increase trace width
- [x] Identify `+5V` power distribution
- [x] Increase trace width
- [x] Verify USB VBUS traces
- [x] Verify motor / load traces
- [x] Re-run **DRC**

---

# 2. Buck Converter Layout (LM2596)
Priority: CRITICAL

The switching loop must be **very compact**.

Components involved:

- U2 — LM2596
- L1 — Inductor
- D3 — Schottky diode
- CIN — input capacitor
- COUT — output capacitor

### Tasks
- [x] Move buck section near `12V_IN`
- [x] Place **input capacitor directly next to LM2596 VIN**
- [x] Place **Schottky diode very close to SW pin**
- [x] Place **inductor immediately after diode**
- [x] Place **output capacitor close to inductor**
- [x] Minimize switching loop area
- [x] Add GND vias near buck converter
- [x] Ensure thick traces for SW and VIN

---

# 3. Decoupling Capacitors
Priority: HIGH

Each IC must have local decoupling.

## MAX7219
Required:
- 100nF ceramic
- 10µF bulk capacitor

### Tasks
- [x] Move 100nF capacitor close to VCC pin
- [x] Move bulk capacitor close to MAX7219
- [x] Ensure short path to GND

## AP2112 (3.3V regulator)

### Tasks
- [x] Ensure input capacitor is next to VIN pin
- [x] Ensure output capacitor is next to VOUT pin
- [x] Verify ground return path is short

---

# 4. Voltage Divider Safety
Priority: HIGH

Current dividers are too close to 3.3V limit.

Example:

10k / 20k ≈ 3.33V when input = 5V (too close to limit)

### Tasks
- [x] Replace dividers with safer ratios

Recommended examples:

| Divider | Output (5V input) |
|---|---|
| 10k / 18k | ~3.2V |
| 12k / 20k | ~3.1V |
| 10k / 15k | ~3.0V |

- [x] Verify turbidity sensor divider
- [x] Verify all analog inputs

---

# 5. I2C Pull-up Resistors
Priority: MEDIUM

Ensure pull-ups exist on:

- SDA
- SCL

### Tasks
- [x] Add resistor SDA → 3.3V
- [x] Add resistor SCL → 3.3V
- [x] Value: **4.7kΩ**

---

# 6. Mounting Holes
Priority: MEDIUM

Required for enclosure / aquarium mounting.

### Tasks
- [x] Add 4 mounting holes
- [x] Place near PCB corners
- [x] Diameter: ~3mm(2,5mm)
- [x] Connect to GND or keep NPTH depending on design(NPTH)

---

# 7. Test Points
Priority: MEDIUM

Add test pads for debugging.

- [x] TP_12V
- [x] TP_5V
- [x] TP_3V3
- [x] TP_GND

---

# 8. USB Power Ports Labeling
Priority: LOW

These USB ports are **power only**.

### Tasks
- [x] Add silk label: `POWER ONLY`
- [x] Add silk label: `5V ONLY`
- [x] Verify VBUS routed correctly
- [x] Ensure polyfuse protection

---

# 9. 12V Distribution Safety
Priority: MEDIUM

Currently using **one polyfuse for entire system**.

Acceptable for Rev.A, but verify current.

### Tasks
- [x] Confirm fuse current rating
- [x] Confirm trace width supports total current
- [x] Verify expected load (LED + pumps + boards)

---

# 10. Silk Screen Improvements
Priority: LOW

### Tasks
- [x] Label polarity on all terminal blocks
- [x] Label sensor ports clearly
- [x] Label expansion connectors
- [x] Ensure text is not hidden under connectors

---

## Extras

### 3D ToDo

- [x] **Add anti-siphon system to the mini peristaltic pump in the aquaponics system**

**What is the siphon effect:**

The siphon effect occurs when water continues to flow even **without the pump being turned on**, solely due to the **difference in height between the reservoirs**.  
If the hose outlet is lower than the water level in the aquarium, gravity can cause a continuous flow.

From: [sketchplanations](https://sketchplanations.com/siphon)

# 3/7/2026 7 AM - PCB Looks Great  

_Time spent: 5.6h_  

Well, I basically finished our ToDo list, fixed the routing and made the necessary lines thicker, tidied up the whole layout and redid the entire track, added the capacitors, fixed the resistors, and added the Mounting Holes + Test Points.


3D:



_Most/almost all notices are screen printed(seringrafia, in pt-br)_

Now, I need to add the siphon break at 3D.

# 3/7/2026 8:09 AM - Disclaimer Siphon  

_Time spent: 0.2h_  

I believe that in our case, since it is a mini peristaltic pump and a small hole, the risk of siphoning is low, but to eliminate any chance of it happening, I will make a small siphon-breaking hole at the top, above the water level.


# 3/7/2026 8:37 AM - Custom PCB   

_Time spent: 0.2h_  

I customized the PCB and now I need to move on to creating the complete BOM, complete documentation, and complete firmware for both boards. The Whale Shark does not need firmware; it is more electrical and management-oriented, while the MAX is controlled by the board.

Updated PCB:
![image] (/user-attachments/blobs/proxy/eyJfcmFpbHMiOnsiZGF0YSI6MTE3MTI3LCJwdXIiOiJibG9iX2lkIn19--02ae7703092ec49e9478bbe4225cba27180b38e8/image.png)

3D:



# 3/9/2026 - Organized project, finalized the BOM, and created firmware  

_Time spent: 17.4h_  

I organized the project a bit more and published it on GitHub. I also managed to finish the entire firmware, although I still need to calibrate a few things and solve some issues that will only be possible once I have the real hardware. While doing that, I also created a diagram of the external electrical part to make things easier to understand:


The lack of a web interface or dashboard is intentional for now in V1. I consider the project, version 1.0.0, to be finished in Beta-ready. At this point, what I really need is the real hardware to continue. I also completed the full BOM and organized it into three separate CSV files with all the prices.

Regarding the size, as I mentioned before, I want to print the 3D parts myself. This gives me some flexibility to make adjustments. The current 3D design is already solid, but printing it myself will allow me to add expansion modules and ports for things like the aquaponics system. About the aquaponics part: I’ll personally cover the pump and the 3D printing for that module. Hopefully I can get the 3D printer through Blueprint itself. The pump is relatively inexpensive, and as mentioned before, it’s an expansion module. I included it on the PCB because it’s one of the project’s main differentiators.

Right now, the “correct” way to interact with SeaLion using the endpoints is through Postman, which I strongly recommend.

The height of the aquarium is determined by the acrylic panel that goes between the two 3D-printed parts. Unfortunately, acrylic tends to be expensive, so I’ll try to source it myself, even if that means using a smaller height or possibly another material as a substitute.

Repo:
https://github.com/TheusHen/Otariinae

Tag with binaries(Firmware):
https://github.com/TheusHen/Otariinae/releases/tag/v1.0.0

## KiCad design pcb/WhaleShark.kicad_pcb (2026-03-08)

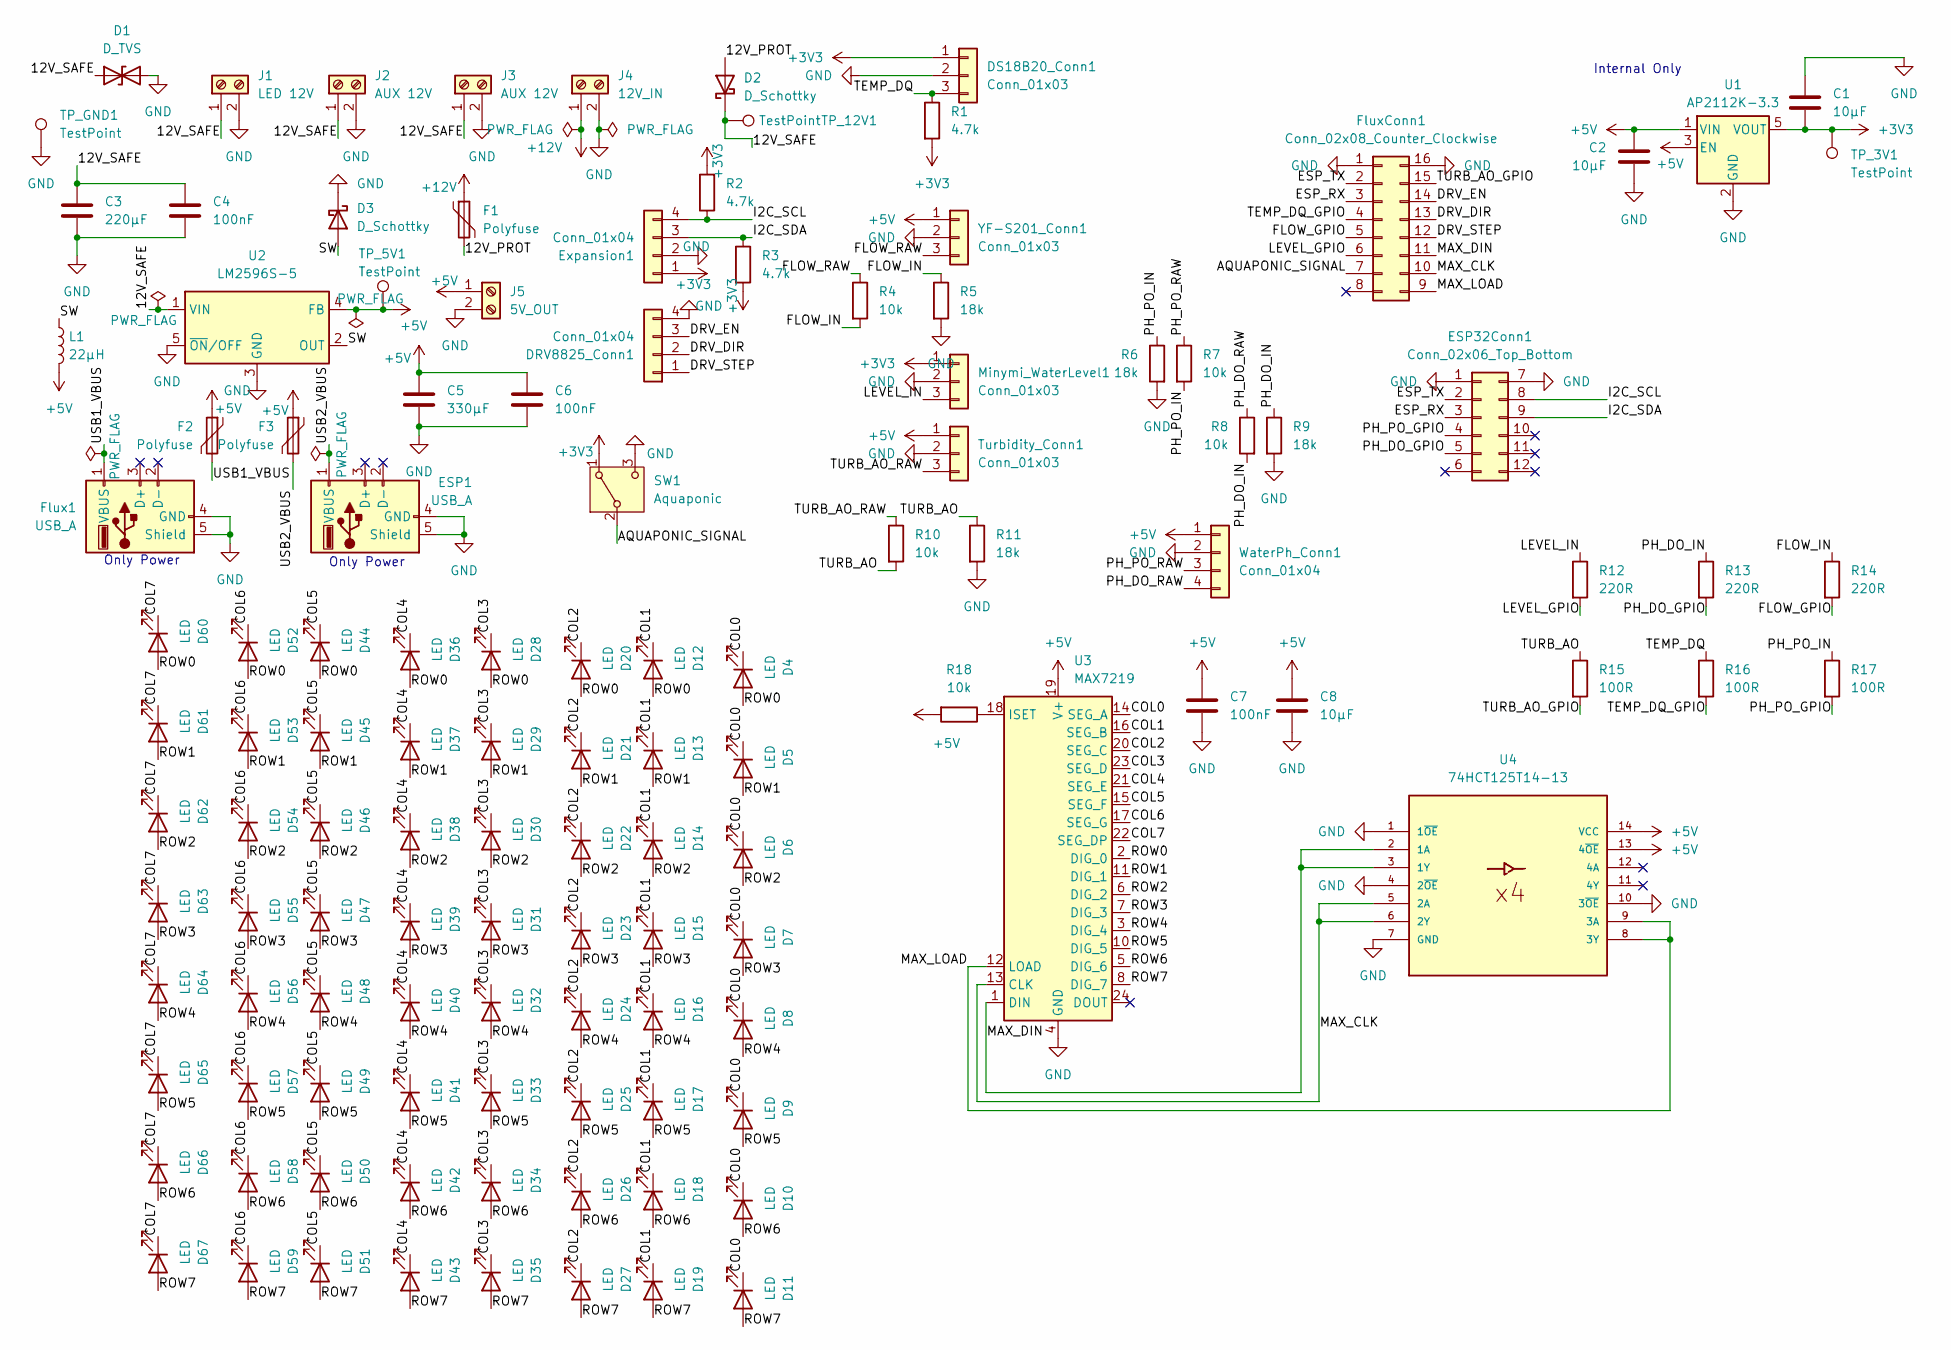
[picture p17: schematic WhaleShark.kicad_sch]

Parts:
C1, C2, C8: 10µF; C_1206_3216Metric
C3: 220µF; CP_Radial_D8.0mm_P3.50mm
C4, C6, C7: 100nF; C_0805_2012Metric
C5: 330µF; CP_Radial_D10.0mm_P5.00mm
D1: D_TVS; D_SMA
D2, D3: D_Schottky; D_SMA
D4, D5, D6, D7, D8, D9, D10, D11, D12, D13, D14, D15, D16, D17, D18, D19, D20, D21, D22, D23, D24, D25, D26, D27, D28, D29, D30, D31, D32, D33, D34, D35, D36, D37, D38, D39, D40, D41, D42, D43, D44, D45, D46, D47, D48, D49, D50, D51, D52, D53, D54, D55, D56, D57, D58, D59, D60, D61, D62, D63, D64, D65, D66, D67: LED; LED_0805_2012Metric
DRV8825_Conn1: Conn_01x04; JST_B4B-XH-A
DS18B20_Conn1: Conn_01x03; JST_B3B-XH-A
ESP1: USB_A; USB_A_Molex_105057_Vertical
ESP32Conn1: Conn_02x06_Top_Bottom; PinHeader_2x06_P2.54mm_Vertical
Expansion1: Conn_01x04; JST_B4B-XH-A
F1, F2, F3: Polyfuse; Fuse_1812_4532Metric
Flux1: USB_A; USB_A_Molex_105057_Vertical
FluxConn1: Conn_02x08_Counter_Clockwise; PinHeader_2x08_P2.54mm_Vertical
J1: LED 12V; HANDSON_KF301-2P
J2, J3: AUX 12V; HANDSON_KF301-2P
J4: 12V_IN; HANDSON_KF301-2P
J5: 5V_OUT; HANDSON_KF301-2P
L1: 22µH; L_6.3x6.3_H3
Minymi_WaterLevel1: Conn_01x03; JST_B3B-XH-A
R1, R2, R3: 4.7k; R_0805_2012Metric
R4, R7, R8, R10, R18: 10k; R_0805_2012Metric
R5, R6, R9, R11: 18k; R_0805_2012Metric
R12, R13, R14: 220R; R_0805_2012Metric
R15, R16, R17: 100R; R_0805_2012Metric
SW1: Aquaponic; 450405020524
TP_3V1, TP_5V1, TP_12V1: TestPoint; TestPoint_Pad_D2.0mm
TP_GND1: TestPoint; TestPoint_Pad_D2.0mm
Turbidity_Conn1: Conn_01x03; JST_B3B-XH-A
U1: AP2112K-3.3; SOT-23-5
U2: LM2596S-5; TO-263-5_TabPin3
U3: MAX7219; SOIC-24W_7.5x15.4mm_P1.27mm
U4: 74HCT125T14-13; TSSOP-14_4.4x5mm_P0.65mm
WaterPh_Conn1: Conn_01x04; JST_B4B-XH-A
YF-S201_Conn1: Conn_01x03; JST_B3B-XH-A

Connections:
+3V3: C1.2, DS18B20_Conn1.1, Expansion1.1, Minymi_WaterLevel1.1, R1.2, R2.2, R3.2, SW1.1 (A), TP_3V1.1, U1.5 (VOUT)
+5V: C2.1, C5.1, C6.1, C7.1, C8.1, F2.1, F3.1, J5.1, L1.2, R18.2, TP_5V1.1, Turbidity_Conn1.1, U1.1 (VIN), U1.3 (EN), U2.4 (FB), U3.19 (V+), U4.13 (4~OE), U4.14 (VCC), WaterPh_Conn1.1, YF-S201_Conn1.1
+12V: F1.1, J4.1
/12V_PROT: D2.2 (A), F1.2
/12V_SAFE: C3.1, C4.1, D1.1 (A1), D2.1 (K), J1.1, J2.1, J3.1, TP_12V1.1, U2.1 (VIN)
/AQUAPONIC_SIGNAL: FluxConn1.7, SW1.2 (B)
/COL0: D4.1 (K), D5.1 (K), D6.1 (K), D7.1 (K), D8.1 (K), D9.1 (K), D10.1 (K), D11.1 (K), U3.14 (SEG_A)
/COL1: D12.1 (K), D13.1 (K), D14.1 (K), D15.1 (K), D16.1 (K), D17.1 (K), D18.1 (K), D19.1 (K), U3.16 (SEG_B)
/COL2: D20.1 (K), D21.1 (K), D22.1 (K), D23.1 (K), D24.1 (K), D25.1 (K), D26.1 (K), D27.1 (K), U3.20 (SEG_C)
/COL3: D28.1 (K), D29.1 (K), D30.1 (K), D31.1 (K), D32.1 (K), D33.1 (K), D34.1 (K), D35.1 (K), U3.23 (SEG_D)
/COL4: D36.1 (K), D37.1 (K), D38.1 (K), D39.1 (K), D40.1 (K), D41.1 (K), D42.1 (K), D43.1 (K), U3.21 (SEG_E)
/COL5: D44.1 (K), D45.1 (K), D46.1 (K), D47.1 (K), D48.1 (K), D49.1 (K), D50.1 (K), D51.1 (K), U3.15 (SEG_F)
/COL6: D52.1 (K), D53.1 (K), D54.1 (K), D55.1 (K), D56.1 (K), D57.1 (K), D58.1 (K), D59.1 (K), U3.17 (SEG_G)
/COL7: D60.1 (K), D61.1 (K), D62.1 (K), D63.1 (K), D64.1 (K), D65.1 (K), D66.1 (K), D67.1 (K), U3.22 (SEG_DP)
/DRV_DIR: DRV8825_Conn1.2, FluxConn1.13
/DRV_EN: DRV8825_Conn1.3, FluxConn1.14
/DRV_STEP: DRV8825_Conn1.1, FluxConn1.12
/ESP_RX: ESP32Conn1.3, FluxConn1.3
/ESP_TX: ESP32Conn1.2, FluxConn1.2
/FLOW_GPIO: FluxConn1.5, R14.2
/FLOW_IN: R4.2, R5.1, R14.1
/FLOW_RAW: R4.1, YF-S201_Conn1.3
/I2C_SCL: ESP32Conn1.8, Expansion1.4, R2.1
/I2C_SDA: ESP32Conn1.9, Expansion1.3, R3.1
/LEVEL_GPIO: FluxConn1.6, R12.2
/LEVEL_IN: Minymi_WaterLevel1.3, R12.1
/MAX_CLK: FluxConn1.10, U3.13 (CLK), U4.5 (2A), U4.6 (2Y)
/MAX_DIN: FluxConn1.11, U3.1 (DIN), U4.2 (1A), U4.3 (1Y)
/MAX_LOAD: FluxConn1.9, U3.12 (LOAD), U4.8 (3Y), U4.9 (3A)
/PH_DO_GPIO: ESP32Conn1.5, R13.2
/PH_DO_IN: R8.2, R9.1, R13.1
/PH_DO_RAW: R8.1, WaterPh_Conn1.4
/PH_PO_GPIO: ESP32Conn1.4, R17.2
/PH_PO_IN: R6.1, R7.2, R17.1
/PH_PO_RAW: R7.1, WaterPh_Conn1.3
/ROW0: D4.2 (A), D12.2 (A), D20.2 (A), D28.2 (A), D36.2 (A), D44.2 (A), D52.2 (A), D60.2 (A), U3.2 (DIG_0)
/ROW1: D5.2 (A), D13.2 (A), D21.2 (A), D29.2 (A), D37.2 (A), D45.2 (A), D53.2 (A), D61.2 (A), U3.11 (DIG_1)
/ROW2: D6.2 (A), D14.2 (A), D22.2 (A), D30.2 (A), D38.2 (A), D46.2 (A), D54.2 (A), D62.2 (A), U3.6 (DIG_2)
/ROW3: D7.2 (A), D15.2 (A), D23.2 (A), D31.2 (A), D39.2 (A), D47.2 (A), D55.2 (A), D63.2 (A), U3.7 (DIG_3)
/ROW4: D8.2 (A), D16.2 (A), D24.2 (A), D32.2 (A), D40.2 (A), D48.2 (A), D56.2 (A), D64.2 (A), U3.3 (DIG_4)
/ROW5: D9.2 (A), D17.2 (A), D25.2 (A), D33.2 (A), D41.2 (A), D49.2 (A), D57.2 (A), D65.2 (A), U3.10 (DIG_5)
/ROW6: D10.2 (A), D18.2 (A), D26.2 (A), D34.2 (A), D42.2 (A), D50.2 (A), D58.2 (A), D66.2 (A), U3.5 (DIG_6)
/ROW7: D11.2 (A), D19.2 (A), D27.2 (A), D35.2 (A), D43.2 (A), D51.2 (A), D59.2 (A), D67.2 (A), U3.8 (DIG_7)
/SW: D3.2 (A), L1.1, U2.2 (OUT)
/TEMP_DQ: DS18B20_Conn1.3, R1.1, R16.1
/TEMP_DQ_GPIO: FluxConn1.4, R16.2
/TURB_AO: R10.2, R11.1, R15.1
/TURB_AO_GPIO: FluxConn1.15, R15.2
/TURB_AO_RAW: R10.1, Turbidity_Conn1.3
/USB1_VBUS: F2.2, Flux1.1 (VBUS)
/USB2_VBUS: ESP1.1 (VBUS), F3.2
GND: C1.1, C2.2, C3.2, C4.2, C5.2, C6.2, C7.2, C8.2, D1.2 (A2), D3.1 (K), DRV8825_Conn1.4, DS18B20_Conn1.2, ESP1.4 (GND), ESP1.5 (Shield), ESP32Conn1.1, ESP32Conn1.7, Expansion1.2, Flux1.4 (GND), Flux1.5 (Shield), FluxConn1.1, FluxConn1.16, J1.2, J2.2, J3.2, J4.2, J5.2, Minymi_WaterLevel1.2, R5.2, R6.2, R9.2, R11.2, SW1.3 (C), TP_GND1.1, Turbidity_Conn1.2, U1.2 (GND), U2.3 (GND), U2.5 (~ON/OFF), U3.4 (GND), U3.9 (GND), U4.1 (1~OE), U4.4 (2~OE), U4.7 (GND), U4.10 (3~OE), WaterPh_Conn1.2, YF-S201_Conn1.2
unnamed: R18.1, U3.18 (ISET)

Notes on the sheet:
Internal Only
Only Power

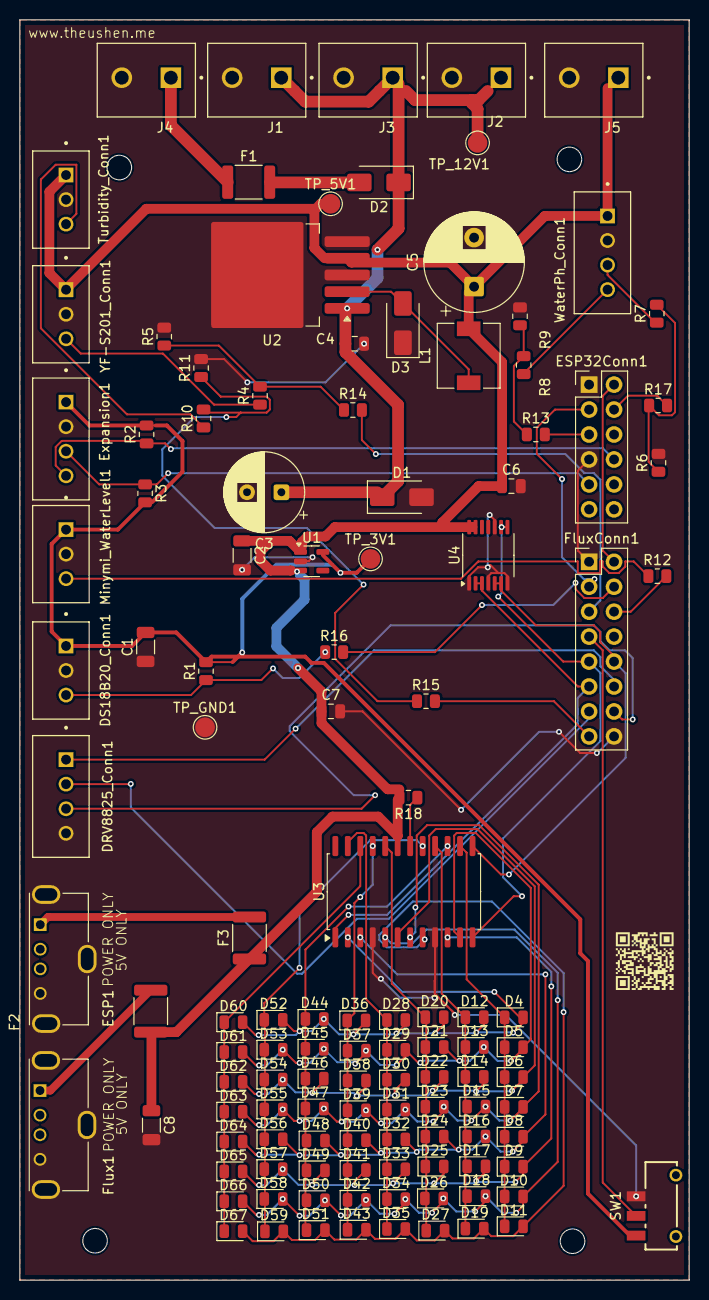
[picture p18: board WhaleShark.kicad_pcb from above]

Board: 2 copper layers, 68.2 x 128.3 mm, 122 parts (0 on the bottom side), 53 nets.

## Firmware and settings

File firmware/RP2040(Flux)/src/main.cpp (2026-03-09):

#include <Arduino.h>
#include <SPI.h>
#include <Wire.h>
#include <SD.h>

#include "pins.h"
#include "config.h"

namespace Proto {
  enum Command : uint8_t {
    CMD_SET_RELAYS      = 0x01,
    CMD_SET_MODE        = 0x02,
    CMD_SET_TEXT        = 0x03,
    CMD_SYNC_EPOCH      = 0x04,
    CMD_SET_BRIGHTNESS  = 0x05,
    CMD_SET_TIMER       = 0x06,
    CMD_PING            = 0x07,
    CMD_SET_ICON        = 0x08,
    CMD_GET_STATUS      = 0x10
  };

  enum MatrixMode : uint8_t {
    MATRIX_IDLE = 0,
    MATRIX_BOOT = 1,
    MATRIX_SCROLL_TEXT = 2,
    MATRIX_TIMER = 3,
    MATRIX_ICON = 4,
    MATRIX_BAR = 5
  };

  enum Icon : uint8_t {
    ICON_OK = 0,
    ICON_WIFI = 1,
    ICON_ALERT = 2,
    ICON_WATER = 3,
    ICON_PLANT = 4,
    ICON_LOADING = 5
  };

  struct StatusFrame {
    uint8_t relaysMask;
    uint8_t mode;
    uint8_t faults;
    uint8_t brightness;
    uint32_t uptimeSeconds;
  } __attribute__((packed));
}

class Max7219Matrix {
public:
  void begin() {
    pinMode(Pins::MAX_CS, OUTPUT);
    pinMode(Pins::MAX_CLK, OUTPUT);
    pinMode(Pins::MAX_DIN, OUTPUT);
    SPI.setRX(Pins::SD_MISO);
    SPI.setTX(Pins::MAX_DIN);
    SPI.setSCK(Pins::MAX_CLK);
    SPI.begin(false);
    writeReg(0x0F, 0x00); // display test off
    writeReg(0x0C, 0x01); // shutdown off
    writeReg(0x0B, 0x07); // scan all digits
    writeReg(0x09, 0x00); // no decode
    setBrightness(Config::DEFAULT_BRIGHTNESS);
    clear();
    push();
  }

  void setBrightness(uint8_t value) {
    brightness = constrain(value, 0, 15);
    writeReg(0x0A, brightness);
  }

  uint8_t getBrightness() const { return brightness; }

  void clear() {
    for (uint8_t i = 0; i < 8; ++i) rows[i] = 0;
  }

  // Logical coordinates match the schematic view requested by the project:
  // x grows left->right, y grows top->bottom.
  // The schematic labels are COL7..COL0 from left to right,
  // so physical bit order is mirrored here intentionally.
  void setPixel(uint8_t x, uint8_t y, bool on) {
    if (x > 7 || y > 7) return;
    uint8_t physicalBit = 7 - x;
    if (on) rows[y] |= (1u << physicalBit);
    else rows[y] &= ~(1u << physicalBit);
  }

  void drawBitmap(const uint8_t bitmap[8]) {
    for (uint8_t y = 0; y < 8; ++y) rows[y] = bitmap[y];
  }

  void drawBar(uint8_t percent) {
    clear();
    uint8_t filled = map(percent, 0, 100, 0, 8);
    for (uint8_t y = 0; y < 8; ++y) {
      for (uint8_t x = 0; x < filled; ++x) setPixel(x, 7 - y, true);
    }
  }

  void push() {
    for (uint8_t i = 0; i < 8; ++i) writeReg(i + 1, rows[i]);
  }

private:
  uint8_t rows[8]{};
  uint8_t brightness = Config::DEFAULT_BRIGHTNESS;

  void writeReg(uint8_t reg, uint8_t value) {
    digitalWrite(Pins::MAX_CS, LOW);
    SPI.transfer(reg);
    SPI.transfer(value);
    digitalWrite(Pins::MAX_CS, HIGH);
  }
};

struct Runtime {
  volatile uint8_t requestedCommand = 0;
  volatile bool packetReady = false;
  volatile uint8_t rxBuffer[40]{};
  volatile size_t rxLen = 0;
  volatile bool statusRequested = false;

  bool sdReady = false;
  bool fluxEnabled = true;
  uint8_t brightness = Config::DEFAULT_BRIGHTNESS;
  uint8_t relayMask = 0;
  uint8_t faults = 0;
  uint8_t matrixMode = Proto::MATRIX_BOOT;

  String scrollText = "BOOT";
  uint32_t timerSeconds = 0;
  uint32_t epochBase = 0;
  uint32_t millisBase = 0;
  unsigned long lastLogMs = 0;
  unsigned long lastHeartbeatMs = 0;
  unsigned long lastMasterPacketMs = 0;
  unsigned long scrollStepMs = 0;
  uint16_t scrollOffset = 0;
  uint8_t bootFrame = 0;
};

Runtime runtime;
Max7219Matrix matrix;
File logFile;

const uint8_t ICON_OK[8] = {
  0b00000000,
  0b00000001,
  0b00000011,
  0b10110110,
  0b01111100,
  0b00111000,
  0b00010000,
  0b00000000,
};
const uint8_t ICON_WIFI[8] = {
  0b00011000,
  0b00100100,
  0b01000010,
  0b00011000,
  0b00100100,
  0b00011000,
  0b00000000,
  0b00011000,
};
const uint8_t ICON_ALERT[8] = {
  0b00011000,
  0b00111100,
  0b00111100,
  0b00111100,
  0b00111100,
  0b00011000,
  0b00000000,
  0b00011000,
};
const uint8_t ICON_WATER[8] = {
  0b00011000,
  0b00111100,
  0b01111110,
  0b01111110,
  0b00111100,
  0b00111100,
  0b00011000,
  0b00000000,
};
const uint8_t ICON_PLANT[8] = {
  0b00011000,
  0b00111100,
  0b00011000,
  0b01011010,
  0b10111101,
  0b00011000,
  0b00011000,
  0b00100100,
};

void setRelayPin(int pin, bool on) {
  digitalWrite(pin, Config::RELAYS_ACTIVE_HIGH ? on : !on);
}

void applyRelayMask(uint8_t mask) {
  runtime.relayMask = mask;
  setRelayPin(Pins::RELAY_MAIN_PUMP, mask & 0x01);
  setRelayPin(Pins::RELAY_AQUAPONICS, mask & 0x02);
  setRelayPin(Pins::RELAY_SPARE1, mask & 0x04);
  setRelayPin(Pins::RELAY_SPARE2, mask & 0x08);
}

uint32_t currentEpoch() {
  if (runtime.epochBase == 0) return 0;
  return runtime.epochBase + ((millis() - runtime.millisBase) / 1000UL);
}

void logLine(const String& line) {
  if (!runtime.sdReady) return;
  logFile = SD.open("/flux_log.csv", FILE_WRITE);
  if (!logFile) return;
  logFile.println(line);
  logFile.close();
}

void drawIcon(uint8_t icon) {
  switch (icon) {
    case Proto::ICON_OK: matrix.drawBitmap(ICON_OK); break;
    case Proto::ICON_WIFI: matrix.drawBitmap(ICON_WIFI); break;
    case Proto::ICON_ALERT: matrix.drawBitmap(ICON_ALERT); break;
    case Proto::ICON_WATER: matrix.drawBitmap(ICON_WATER); break;
    case Proto::ICON_PLANT: matrix.drawBitmap(ICON_PLANT); break;
    default: {
      matrix.clear();
      for (uint8_t i = 0; i <= runtime.bootFrame; ++i) matrix.setPixel(i, 3, true);
      break;
    }
  }
  matrix.push();
}

const uint8_t* glyphFor(char c) {
  static const uint8_t blank[5] = {0,0,0,0,0};
  static const uint8_t digits[10][5] = {
    {0x3E,0x51,0x49,0x45,0x3E}, {0x00,0x42,0x7F,0x40,0x00}, {0x62,0x51,0x49,0x49,0x46},
    {0x22,0x49,0x49,0x49,0x36}, {0x18,0x14,0x12,0x7F,0x10}, {0x2F,0x49,0x49,0x49,0x31},
    {0x3E,0x49,0x49,0x49,0x32}, {0x01,0x71,0x09,0x05,0x03}, {0x36,0x49,0x49,0x49,0x36},
    {0x26,0x49,0x49,0x49,0x3E}
  };
  static const uint8_t letters[][5] = {
    {0x7E,0x11,0x11,0x11,0x7E}, // A
    {0x7F,0x49,0x49,0x49,0x36}, // B
    {0x3E,0x41,0x41,0x41,0x22}, // C
    {0x7F,0x41,0x41,0x22,0x1C}, // D
    {0x7F,0x49,0x49,0x49,0x41}, // E
    {0x7F,0x09,0x09,0x09,0x01}, // F
    {0x3E,0x41,0x49,0x49,0x7A}, // G
    {0x7F,0x08,0x08,0x08,0x7F}, // H
    {0x00,0x41,0x7F,0x41,0x00}, // I
    {0x20,0x40,0x41,0x3F,0x01}, // J
    {0x7F,0x08,0x14,0x22,0x41}, // K
    {0x7F,0x40,0x40,0x40,0x40}, // L
    {0x7F,0x02,0x0C,0x02,0x7F}, // M
    {0x7F,0x04,0x08,0x10,0x7F}, // N
    {0x3E,0x41,0x41,0x41,0x3E}, // O
    {0x7F,0x09,0x09,0x09,0x06}, // P
    {0x3E,0x41,0x51,0x21,0x5E}, // Q
    {0x7F,0x09,0x19,0x29,0x46}, // R
    {0x26,0x49,0x49,0x49,0x32}, // S
    {0x01,0x01,0x7F,0x01,0x01}, // T
    {0x3F,0x40,0x40,0x40,0x3F}, // U
    {0x1F,0x20,0x40,0x20,0x1F}, // V
    {0x7F,0x20,0x18,0x20,0x7F}, // W
    {0x63,0x14,0x08,0x14,0x63}, // X
    {0x03,0x04,0x78,0x04,0x03}, // Y
    {0x61,0x51,0x49,0x45,0x43}  // Z
  };
  if (c >= '0' && c <= '9') return digits[c - '0'];
  if (c >= 'A' && c <= 'Z') return letters[c - 'A'];
  if (c >= 'a' && c <= 'z') return letters[c - 'a'];
  return blank;
}

void drawScrollTextFrame(const String& text, uint16_t pixelOffset) {
  matrix.clear();
  uint16_t cursor = 0;
  for (size_t idx = 0; idx < text.length(); ++idx) {
    const uint8_t* glyph = glyphFor(text[idx]);
    for (uint8_t col = 0; col < 5; ++col) {
      int16_t logicalX = cursor + col - pixelOffset;
      if (logicalX >= 0 && logicalX < 8) {
        uint8_t columnBits = glyph[col];
        for (uint8_t row = 0; row < 7; ++row) {
          bool on = columnBits & (1u << row);
          matrix.setPixel(logicalX, row, on);
        }
      }
    }
    cursor += 6;
  }
  matrix.push();
}

void drawTimer(uint32_t seconds) {
  // MM or SS compact display on 8x8.
  char buf[3];
  uint32_t value = seconds >= 60 ? (seconds + 59) / 60 : seconds;
  snprintf(buf, sizeof(buf), "%02lu", (unsigned long)(value % 100));
  matrix.clear();
  drawScrollTextFrame(String(buf), 0);
}

void updateMatrix() {
  switch (runtime.matrixMode) {
    case Proto::MATRIX_BOOT: {
      matrix.clear();
      for (uint8_t i = 0; i <= runtime.bootFrame; ++i) {
        matrix.setPixel(i, 2, true);
        matrix.setPixel(i, 5, true);
      }
      runtime.bootFrame = (runtime.bootFrame + 1) % 8;
      matrix.push();
      break;
    }
    case Proto::MATRIX_SCROLL_TEXT: {
      if (millis() - runtime.scrollStepMs > 90) {
        runtime.scrollStepMs = millis();
        runtime.scrollOffset++;
      }
      uint16_t totalWidth = runtime.scrollText.length() * 6 + 8;
      if (runtime.scrollOffset > totalWidth) runtime.scrollOffset = 0;
      drawScrollTextFrame(runtime.scrollText, runtime.scrollOffset);
      break;
    }
    case Proto::MATRIX_TIMER: {
      drawTimer(runtime.timerSeconds);
      matrix.push();
      break;
    }
    case Proto::MATRIX_ICON:
    case Proto::MATRIX_IDLE:
    case Proto::MATRIX_BAR:
    default:
      break;
  }
}

void onReceive(int count) {
  runtime.rxLen = 0;
  while (Wire.available() && runtime.rxLen < sizeof(runtime.rxBuffer)) {
    runtime.rxBuffer[runtime.rxLen++] = Wire.read();
  }
  runtime.packetReady = true;
  runtime.lastMasterPacketMs = millis();
}

void onRequest() {
  Proto::StatusFrame status{};
  status.relaysMask = runtime.relayMask;
  status.mode = runtime.matrixMode;
  status.faults = runtime.faults;
  status.brightness = runtime.brightness;
  status.uptimeSeconds = millis() / 1000UL;
  Wire.write(reinterpret_cast<const uint8_t*>(&status), sizeof(status));
}

void processPacket() {
  if (!runtime.packetReady || runtime.rxLen == 0) return;
  noInterrupts();
  uint8_t buffer[40]{};
  size_t len = runtime.rxLen;
  memcpy(buffer, (const void*)runtime.rxBuffer, len);
  runtime.packetReady = false;
  interrupts();

  uint8_t cmd = buffer[0];
  switch (cmd) {
    case Proto::CMD_SET_RELAYS:
      if (len >= 2) applyRelayMask(buffer[1]);
      break;
    case Proto::CMD_SET_MODE:
      if (len >= 2) runtime.matrixMode = buffer[1];
      break;
    case Proto::CMD_SET_TEXT:
      if (len >= 2) {
        uint8_t textLen = min<uint8_t>(buffer[1], len - 2);
        runtime.scrollText = "";
        for (uint8_t i = 0; i < textLen; ++i) runtime.scrollText += char(buffer[2 + i]);
        runtime.scrollOffset = 0;
        runtime.matrixMode = Proto::MATRIX_SCROLL_TEXT;
      }
      break;
    case Proto::CMD_SYNC_EPOCH:
      if (len >= 5) {
        uint32_t epoch;
        memcpy(&epoch, buffer + 1, sizeof(uint32_t));
        runtime.epochBase = epoch;
        runtime.millisBase = millis();
      }
      break;
    case Proto::CMD_SET_BRIGHTNESS:
      if (len >= 2) {
        runtime.brightness = buffer[1] & 0x0F;
        matrix.setBrightness(runtime.brightness);
      }
      break;
    case Proto::CMD_SET_TIMER:
      if (len >= 5) {
        memcpy(&runtime.timerSeconds, buffer + 1, sizeof(uint32_t));
        runtime.matrixMode = Proto::MATRIX_TIMER;
      }
      break;
    case Proto::CMD_SET_ICON:
      if (len >= 2) {
        runtime.matrixMode = Proto::MATRIX_ICON;
        drawIcon(buffer[1]);
      }
      break;
    case Proto::CMD_PING:
      break;
    default:
      runtime.faults |= 0x01;
      break;
  }
}

void checkFailsafe() {
  bool enabled = digitalRead(Pins::ENABLE_IN) == HIGH;
  runtime.fluxEnabled = enabled;

  bool stale = (millis() - runtime.lastMasterPacketMs) > Config::FAILSAFE_TIMEOUT_MS;
  if (!enabled || stale) {
    uint8_t safeMask = 0;
    if (Config::SAFE_MAIN_PUMP_ON_IF_LINK_LOST) safeMask |= 0x01;
    if (!Config::SAFE_AQUAPONICS_OFF_IF_LINK_LOST) safeMask |= 0x02;
    applyRelayMask(safeMask);
    if (stale) runtime.faults |= 0x02;
    drawIcon(Proto::ICON_ALERT);
  }
}

void logPeriodicState() {
  if (!runtime.sdReady) return;
  if (millis() - runtime.lastLogMs < Config::LOG_PERIOD_MS) return;
  runtime.lastLogMs = millis();
  String line = String(currentEpoch()) + "," +
                String(millis()) + "," +
                String(runtime.relayMask) + "," +
                String(runtime.matrixMode) + "," +
                String(runtime.faults) + "," +
                String(digitalRead(Pins::SD_DET) == LOW ? 1 : 0);
  logLine(line);
}

void heartbeat() {
  if (millis() - runtime.lastHeartbeatMs < Config::HEARTBEAT_PERIOD_MS) return;
  runtime.lastHeartbeatMs = millis();
  digitalWrite(Pins::STATUS_INT, !digitalRead(Pins::STATUS_INT));
}

void setup() {
  Serial.begin(115200);

  pinMode(Pins::RELAY_MAIN_PUMP, OUTPUT);
  pinMode(Pins::RELAY_AQUAPONICS, OUTPUT);
  pinMode(Pins::RELAY_SPARE1, OUTPUT);
  pinMode(Pins::RELAY_SPARE2, OUTPUT);
  pinMode(Pins::STATUS_INT, OUTPUT);
  pinMode(Pins::ENABLE_IN, INPUT_PULLUP);
  pinMode(Pins::SD_DET, INPUT_PULLUP);

  applyRelayMask(0x00);

  matrix.begin();
  matrix.setBrightness(Config::DEFAULT_BRIGHTNESS);

  SPI1.setRX(Pins::SD_MISO);
  SPI1.setTX(Pins::SD_MOSI);
  SPI1.setSCK(Pins::SD_SCK);
  SPI1.begin(false);
  runtime.sdReady = SD.begin(Pins::SD_CS, SPI1);
  if (runtime.sdReady) {
    logLine("epoch,millis,relay_mask,matrix_mode,faults,sd_present");
  }

  Wire.setSDA(Pins::I2C_SDA);
  Wire.setSCL(Pins::I2C_SCL);
  Wire.begin(Config::I2C_ADDRESS);
  Wire.onReceive(onReceive);
  Wire.onRequest(onRequest);

  runtime.lastMasterPacketMs = millis();
}

void loop() {
  processPacket();
  updateMatrix();
  heartbeat();
  checkFailsafe();
  logPeriodicState();

  if (runtime.matrixMode == Proto::MATRIX_TIMER && runtime.timerSeconds > 0) {
    static unsigned long lastTick = 0;
    if (millis() - lastTick >= 1000) {
      lastTick = millis();
      runtime.timerSeconds--;
    }
  }

  delay(10);
}

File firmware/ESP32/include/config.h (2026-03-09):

#pragma once
#include <Arduino.h>

namespace Config {
  static constexpr const char* WIFI_SSID = "CHANGE_ME";
  static constexpr const char* WIFI_PASSWORD = "CHANGE_ME";

  // Optional. If empty, endpoints are open on the local network.
  static constexpr const char* API_SECRET = "CHANGE_ME_OPTIONAL";

  static constexpr const char* HOSTNAME = "sealion-whaleshark";
  static constexpr const char* TZ = "<+03>-3"; // replaced at runtime by POSIX TZ string for Sao Paulo
  static constexpr const char* POSIX_TZ_SAO_PAULO = "<-03>3";
  static constexpr const char* NTP1 = "pool.ntp.org";
  static constexpr const char* NTP2 = "time.google.com";

  static constexpr uint8_t FLUX_I2C_ADDR = 0x12;

  static constexpr unsigned long WIFI_RETRY_MS = 15000;
  static constexpr unsigned long SENSOR_PERIOD_MS = 2000;
  static constexpr unsigned long STATUS_PUSH_MS = 2000;
  static constexpr unsigned long TIME_SYNC_MS = 15 * 60 * 1000UL;
  static constexpr unsigned long AUTOMATION_TICK_MS = 1000;

  static constexpr bool ENABLE_WATER_TEMP = true;
  static constexpr bool ENABLE_PH = true;
  static constexpr bool ENABLE_TDS = true;
  static constexpr bool ENABLE_TURBIDITY = true;
  static constexpr bool ENABLE_WATER_LEVEL_LOW = true;
  static constexpr bool ENABLE_WATER_LEVEL_HIGH = true;

  // ADC conversion placeholders. These must be calibrated on the real hardware.
  static constexpr float ADC_REF_V = 3.3f;
  static constexpr float ADC_MAX = 4095.0f;

  static constexpr bool RELAYS_ACTIVE_HIGH = true;

  // Main aquarium pump philosophy:
  // keep it ON by default for circulation and filtration.
  static constexpr bool MAIN_PUMP_DEFAULT_ON = true;

  // If low water is detected, skip aquaponics and optionally stop the main pump to avoid dry running.
  static constexpr bool STOP_MAIN_PUMP_ON_LOW_LEVEL = true;

  // Aquaponics defaults for V1.
  // Tiny peristaltic pump, conservative schedule.
  static constexpr bool AQUAPONICS_ENABLED_DEFAULT = true;
  static constexpr uint16_t AQUAPONICS_RUN_SECONDS = 60;
  static constexpr uint16_t AQUAPONICS_INTERVAL_MINUTES = 120;
  static constexpr uint8_t AQUAPONICS_DAY_START_HOUR = 8;
  static constexpr uint8_t AQUAPONICS_DAY_END_HOUR = 20;

  static constexpr uint8_t MATRIX_BRIGHTNESS = 6;
}

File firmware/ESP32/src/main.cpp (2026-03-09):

#include <Arduino.h>
#include <WiFi.h>
#include <WebServer.h>
#include <Wire.h>
#include <time.h>
#ifdef ESP32
#include <OneWire.h>
#include <DallasTemperature.h>
#endif

#include "pins.h"
#include "config.h"

namespace FluxProto {
  enum Command : uint8_t {
    CMD_SET_RELAYS      = 0x01,
    CMD_SET_MODE        = 0x02,
    CMD_SET_TEXT        = 0x03,
    CMD_SYNC_EPOCH      = 0x04,
    CMD_SET_BRIGHTNESS  = 0x05,
    CMD_SET_TIMER       = 0x06,
    CMD_PING            = 0x07,
    CMD_SET_ICON        = 0x08,
    CMD_GET_STATUS      = 0x10
  };

  enum MatrixMode : uint8_t {
    MATRIX_IDLE = 0,
    MATRIX_BOOT = 1,
    MATRIX_SCROLL_TEXT = 2,
    MATRIX_TIMER = 3,
    MATRIX_ICON = 4,
    MATRIX_BAR = 5
  };

  enum Icon : uint8_t {
    ICON_OK = 0,
    ICON_WIFI = 1,
    ICON_ALERT = 2,
    ICON_WATER = 3,
    ICON_PLANT = 4,
    ICON_LOADING = 5
  };

  struct StatusFrame {
    uint8_t relaysMask;
    uint8_t mode;
    uint8_t faults;
    uint8_t brightness;
    uint32_t uptimeSeconds;
  } __attribute__((packed));
}

enum class SystemMode : uint8_t {
  AUTO,
  MANUAL,
  MAINTENANCE
};

struct SensorState {
  float waterTempC = NAN;
  float ph = NAN;
  float tdsPpm = NAN;
  float turbidityPct = NAN;
  int ambientLightRaw = 0;
  bool lowLevel = false;
  bool highLevel = false;
  unsigned long lastReadMs = 0;
};

struct AutomationState {
  bool mainPump = Config::MAIN_PUMP_DEFAULT_ON;
  bool aquaponicsPump = false;
  bool spare1 = false;
  bool spare2 = false;
  bool aquaponicsEnabled = Config::AQUAPONICS_ENABLED_DEFAULT;
  time_t lastAquaponicsStart = 0;
  time_t lastTimeSync = 0;
};

struct RuntimeState {
  bool wifiConnected = false;
  bool ntpValid = false;
  bool fluxOnline = false;
  bool fluxEnabled = true;
  bool authEnabled = true;
  String lastMatrixText = "BOOT";
  SystemMode mode = SystemMode::AUTO;
};

WebServer server(80);
SensorState sensors;
AutomationState autoState;
RuntimeState runtime;

OneWire oneWire(Pins::WATER_TEMP_ONEWIRE);
DallasTemperature dallas(&oneWire);

static unsigned long lastSensorPoll = 0;
static unsigned long lastStatusPush = 0;
static unsigned long lastWifiAttempt = 0;
static unsigned long lastAutomationTick = 0;

bool hasApiSecret() {
  const char* secret = Config::API_SECRET;
  return secret && strlen(secret) > 0 && String(secret) != "CHANGE_ME_OPTIONAL";
}

bool checkAuth() {
  runtime.authEnabled = hasApiSecret();
  if (!runtime.authEnabled) return true;
  String header = server.header("X-API-Key");
  return header == String(Config::API_SECRET);
}

String modeToString(SystemMode mode) {
  switch (mode) {
    case SystemMode::AUTO: return "auto";
    case SystemMode::MANUAL: return "manual";
    case SystemMode::MAINTENANCE: return "maintenance";
  }
  return "unknown";
}

bool sendFluxPacket(const uint8_t* data, size_t len) {
  Wire.beginTransmission(Config::FLUX_I2C_ADDR);
  size_t written = Wire.write(data, len);
  uint8_t rc = Wire.endTransmission();
  runtime.fluxOnline = (rc == 0 && written == len);
  return runtime.fluxOnline;
}

bool fluxSetRelays(bool mainPump, bool aquaponics, bool spare1, bool spare2) {
  uint8_t mask = 0;
  if (mainPump) mask |= 0x01;
  if (aquaponics) mask |= 0x02;
  if (spare1) mask |= 0x04;
  if (spare2) mask |= 0x08;

  uint8_t packet[] = { FluxProto::CMD_SET_RELAYS, mask };
  return sendFluxPacket(packet, sizeof(packet));
}

bool fluxSetMode(uint8_t mode) {
  uint8_t packet[] = { FluxProto::CMD_SET_MODE, mode };
  return sendFluxPacket(packet, sizeof(packet));
}

bool fluxSetIcon(uint8_t icon) {
  uint8_t packet[] = { FluxProto::CMD_SET_ICON, icon };
  return sendFluxPacket(packet, sizeof(packet));
}

bool fluxSetBrightness(uint8_t value) {
  uint8_t packet[] = { FluxProto::CMD_SET_BRIGHTNESS, value };
  return sendFluxPacket(packet, sizeof(packet));
}

bool fluxSetTimer(uint32_t secondsRemaining) {
  uint8_t packet[1 + sizeof(uint32_t)] = { FluxProto::CMD_SET_TIMER };
  memcpy(packet + 1, &secondsRemaining, sizeof(uint32_t));
  return sendFluxPacket(packet, sizeof(packet));
}

bool fluxScrollText(const String& text) {
  String trimmed = text.substring(0, 32);
  uint8_t len = static_cast<uint8_t>(trimmed.length());
  uint8_t packet[2 + 32] = { FluxProto::CMD_SET_TEXT, len };
  memcpy(packet + 2, trimmed.c_str(), len);
  runtime.lastMatrixText = trimmed;
  return sendFluxPacket(packet, 2 + len);
}

bool fluxSyncEpoch(time_t epoch) {
  uint8_t packet[1 + sizeof(uint32_t)] = { FluxProto::CMD_SYNC_EPOCH };
  uint32_t e = static_cast<uint32_t>(epoch);
  memcpy(packet + 1, &e, sizeof(uint32_t));
  autoState.lastTimeSync = epoch;
  return sendFluxPacket(packet, sizeof(packet));
}

bool fluxGetStatus(FluxProto::StatusFrame& out) {
  Wire.beginTransmission(Config::FLUX_I2C_ADDR);
  Wire.write(static_cast<uint8_t>(FluxProto::CMD_GET_STATUS));
  if (Wire.endTransmission(false) != 0) {
    runtime.fluxOnline = false;
    return false;
  }
  const size_t need = sizeof(FluxProto::StatusFrame);
  size_t got = Wire.requestFrom((int)Config::FLUX_I2C_ADDR, (int)need);
  if (got != need) {
    runtime.fluxOnline = false;
    return false;
  }
  uint8_t* dst = reinterpret_cast<uint8_t*>(&out);
  for (size_t i = 0; i < need; ++i) dst[i] = Wire.read();
  runtime.fluxOnline = true;
  return true;
}

float readAdcVoltage(int pin) {
  uint16_t raw = analogRead(pin);
  return (static_cast<float>(raw) * Config::ADC_REF_V) / Config::ADC_MAX;
}

float estimatePh() {
  float v = readAdcVoltage(Pins::PH_ADC);
  return 7.0f + ((2.50f - v) * 3.0f);
}

float estimateTds() {
  float v = readAdcVoltage(Pins::TDS_ADC);
  float compensation = 1.0f;
  if (!isnan(sensors.waterTempC)) compensation = 1.0f + 0.02f * (sensors.waterTempC - 25.0f);
  float compensatedV = v / compensation;
  float tds = (133.42f * compensatedV * compensatedV * compensatedV
             - 255.86f * compensatedV * compensatedV
             + 857.39f * compensatedV) * 0.5f;
  return max(0.0f, tds);
}

float estimateTurbidityPct() {
  float v = readAdcVoltage(Pins::TURBIDITY_ADC);
  float pct = (1.0f - constrain(v / 3.0f, 0.0f, 1.0f)) * 100.0f;
  return constrain(pct, 0.0f, 100.0f);
}

void pollSensors() {
  if (Config::ENABLE_WATER_TEMP) {
    dallas.requestTemperatures();
    float t = dallas.getTempCByIndex(0);
    if (t > -50.0f && t < 120.0f) sensors.waterTempC = t;
  }
  if (Config::ENABLE_PH) sensors.ph = estimatePh();
  if (Config::ENABLE_TDS) sensors.tdsPpm = estimateTds();
  if (Config::ENABLE_TURBIDITY) sensors.turbidityPct = estimateTurbidityPct();
  sensors.ambientLightRaw = analogRead(Pins::AMBIENT_LIGHT_ADC);
  if (Config::ENABLE_WATER_LEVEL_LOW) sensors.lowLevel = digitalRead(Pins::WATER_LEVEL_LOW) == LOW;
  if (Config::ENABLE_WATER_LEVEL_HIGH) sensors.highLevel = digitalRead(Pins::WATER_LEVEL_HIGH) == LOW;
  sensors.lastReadMs = millis();
}

bool isWithinAquaponicsWindow(struct tm* tminfo) {
  if (!tminfo) return true;
  int h = tminfo->tm_hour;
  return h >= Config::AQUAPONICS_DAY_START_HOUR && h < Config::AQUAPONICS_DAY_END_HOUR;
}
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

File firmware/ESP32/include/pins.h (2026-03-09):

#pragma once

// WhaleShark (ESP32) recommended V1 mapping.
// Chosen to avoid typical ESP32 flash / boot-strap trouble.

namespace Pins {
  static constexpr int I2C_SDA = 21;
  static constexpr int I2C_SCL = 22;

  static constexpr int FLUX_INT = 27;      // Flux -> WhaleShark status / fault hint
  static constexpr int FLUX_ENABLE = 26;   // WhaleShark -> Flux enable / maintenance request

  // Optional local sensors on WhaleShark.
  static constexpr int WATER_TEMP_ONEWIRE = 4;
  static constexpr int WATER_LEVEL_LOW = 32;
  static constexpr int WATER_LEVEL_HIGH = 33;
  static constexpr int PH_ADC = 34;
  static constexpr int TDS_ADC = 35;
  static constexpr int TURBIDITY_ADC = 36;
  static constexpr int AMBIENT_LIGHT_ADC = 39;
}

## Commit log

2026-03-08 Revise BOM.csv with updated product information
    Updated BOM.csv to include new product details and pricing.
    [BOM.csv]
2026-03-08 Update and rename BOM.csv to bom_parts_eletrical.csv
    [BOM.csv, bom_parts_eletrical.csv]
2026-03-08 Add BOM files and connection documentation for Flux and WhaleShark integration
    [bom_parts_eletrical.csv, bom_parts_pcb_mouser.csv, bom_total.csv]
2026-03-08 Enhance README.md with structured 3D and PCB images for better visualization
2026-03-09 Add firmware for WhaleShark (ESP32) and RP2040 (Flux) with initial configurations and sensor handling
    - Created pins.h and config.h for both ESP32 and RP2040 with appropriate pin mappings and configuration settings.
    - Implemented main.cpp for ESP32 with WiFi, web server, and sensor management including temperature, pH, TDS, turbidity, and ambient light.
    - Added command protocol for communication with Flux and implemented relay control and automation logic.
    - Developed Max7219Matrix class for handling LED matrix display on RP2040, including drawing icons and scrolling text.
    - Integrated SD card logging functionality in RP2040 firmware.
    - Established I2C communication for both platforms to fac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
2026-03-09 Fixed build errors, added new libs and updated .gitignore
    [config.h]
